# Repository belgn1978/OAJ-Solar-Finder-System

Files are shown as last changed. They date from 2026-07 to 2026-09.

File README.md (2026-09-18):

# OAJ Solar Finder System

A modular, 3D-printable projection finder for safely aligning a filtered telescope with the Sun. The telescope-specific foot is separated from the universal finder body, so future adapters can reuse the same optical assembly.

## Prototype P1

P1 is ready for its first fit and sunlight test. The printable set contains:

- `OAJ_SFS_P1_body.stl` — universal 90 mm finder body
- `OAJ_SFS_P1_nacatin_adapter.stl` — adapter for the measured Nacatin 90/800 finder shoe
- `OAJ_SFS_P1_pinhole_plate.stl` — removable front plate with a 0.8 mm pilot aperture
- `OAJ_SFS_P1_target_plate.stl` — pale rear target with recessed crosshair

The source is fully parametric in `openscad/solar_finder.scad`. Select a component with the `part` variable or run `scripts/export_stls.sh` to rebuild the complete STL set.

## How it works

Sunlight passes through the small front aperture and projects a spot onto the rear target. Centre the spot on the recessed crosshair to align the telescope. Six target positions provide pinhole-to-target distances from 45 mm to 70 mm.

## Important safety warning

This finder is a pointing aid only. It is **not** an eye-safe solar filter.

- Never look through the pinhole.
- Never look through an unfiltered telescope or finder.
- Fit a secure, certified full-aperture solar filter to the telescope before pointing it toward the Sun.
- Inspect the filter and its retention before every session.
- Supervise children continuously.

## Prototype status

The universal parts are dimensionally complete and their STL meshes have been checked as closed/manifold. The Nacatin foot is based on supplied measurements; its 5.5 mm height was estimated from photographs and must be verified by the first fit test.

See [`docs/P1_PRINT_AND_TEST_GUIDE.md`](docs/P1_PRINT_AND_TEST_GUIDE.md) before ordering or using the prototype.

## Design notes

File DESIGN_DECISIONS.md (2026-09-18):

<!-- @format -->

# Design Decisions

This document records the major architectural decisions made during the development of the OAJ Solar Finder System.

---

## DD-001

### Decision

Use a modular adapter system instead of making the telescope foot part of the main body.

### Reason

- Supports multiple telescope brands.
- Reduces waste.
- Only the adapter needs replacing when changing telescopes.
- Cheaper to manufacture and ship.
- Easier to improve individual adapters.
- Allows future accessories to use the same interface.

### Status

Approved

---

## DD-002

### Decision

Use a captured sliding dovetail with 0.25 mm clearance per side for the universal adapter interface.

### Reason

- The body cannot lift away from the adapter during use.
- The adapter prints without support.
- Fit can be tuned with one parameter after P1 testing.
- A positive front stop makes insertion repeatable.

### Status

Approved for P1

---

## DD-003

### Decision

Use separate removable pinhole and target plates, with six rigid target positions from 45 mm to 70 mm.

### Reason

- Plates can print flat for cleaner apertures and markings.
- Damaged plates can be replaced without reprinting the body.
- Multiple distances allow the first sunlight test to identify the clearest spot.
- Rigid slots are simpler and safer to validate than a folding mechanism.

### Status

Approved for P1

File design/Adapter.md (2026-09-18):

<!-- @format -->

# Adapter Design

## Purpose

The adapter connects the solar finder to a specific telescope.

Only the adapter changes between telescope models.

The rest of the system remains identical.

---

## Supported Telescopes

- Nacatin 90/800 (Current)
- Sky-Watcher (Future)
- Celestron (Future)
- SVBONY (Future)

---

## Current Measurements

### Nacatin Finder Foot

Length: 39.3 mm

Top Width: 23.8 mm

Bottom Width:
28.4 mm front
29.5 mm rear

Approx Height:
5.5 mm

Rear Notch

Width: 14.9 mm

Length: 4.2 mm

Depth: 3.5 mm

---

## Prototype geometry

The P1 adapter reproduces the measured tapered foot and rear locating notch. A short pedestal carries the universal captured-dovetail tongue above the telescope shoe.

The estimated 5.5 mm foot height is deliberately isolated in the parametric OpenSCAD source so it can be corrected after the first fit test without redesigning the universal body.

## Status

P1 STL generated; physical fit validation pending.

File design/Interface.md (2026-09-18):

<!-- @format -->

# Interface Design

## Purpose

The interface is the heart of the OAJ Solar Finder System.

Every telescope adapter connects to the main body using exactly the same interface.

This means the main body never needs redesigning when supporting a new telescope.

---

## Design Goals

- Universal connection
- Easy to print
- Strong
- Minimal supports
- Beginner friendly
- Replaceable adapters

---

## Version

Current Version: P1

---

## P1 specification

- Captured male dovetail on each telescope adapter
- Rear-entry female socket in the universal body
- 22 mm engagement length
- 16 mm neck width and 20 mm head width
- 4.5 mm dovetail height
- 0.25 mm clearance per side
- Positive front insertion stop

---

## Future Improvements

- Locking button or clip after physical fit testing
- Magnetic retention
- Quick release

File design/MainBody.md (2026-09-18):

<!-- @format -->

# Main Body

## Purpose

The main body is the permanent part of the system.

It accepts interchangeable adapters underneath and removable target plates above.

---

## P1 contains

- Adapter socket
- Six target positions at 45, 50, 55, 60, 65, and 70 mm
- Front plate mount
- Rear plate slots
- Weight-reduction pockets

---

## Design Goals

- Printable without supports
- Lightweight
- Strong
- Easy assembly
- Modular

---

## Status

P1 STL generated and mesh validated.

## Future features

- Folding plates
- Adjustable pinhole
- Optional locking clip
- Colour inserts

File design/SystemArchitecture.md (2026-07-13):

<!-- @format -->

# System Architecture

## Overview

The OAJ Solar Finder System (SFS) is designed as a modular accessory system.

The objective is to separate telescope-specific components from the universal finder body.

---

## High Level Architecture

```text
                   Rear Plate
                        ▲
                        │
                 Slides into
                        │
        ┌────────────────────────┐
        │                        │
        │      Main Body         │
        │                        │
        └────────────┬───────────┘
                     │
           Universal Interface
                     │
        ┌────────────┴───────────┐
        │                        │
        │    Telescope Adapter   │
        │                        │
        └────────────┬───────────┘
                     │
             Telescope Finder Shoe
```

---

## Core Principles

- Modular
- Easy to print
- Replaceable components
- Universal interface
- Low cost
- Beginner friendly

---

## Current Status

Architecture Design

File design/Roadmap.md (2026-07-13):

<!-- @format -->

# Roadmap

## Version 0.1

Project Setup

- Repository created
- Git configured
- VS Code configured
- OpenSCAD configured

---

## Version 0.2

Architecture

- Modular interface
- Adapter specification
- Main body specification

---

## Version 0.3

CAD

- Adapter
- Main body
- Front plate
- Rear plate

---

## Version 0.4

Prototype

- First printable version
- Initial fit testing
- Adjustment

---

## Version 0.5

Field Testing

- Solar alignment
- Ease of use
- Eclipse testing

---

## Version 1.0

Release Candidate

- Final adjustments
- Documentation
- STL release

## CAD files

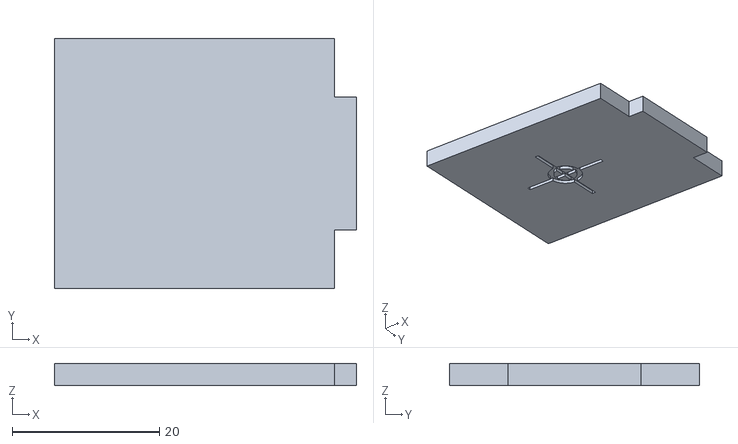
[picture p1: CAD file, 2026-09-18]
stl/OAJ_SFS_P1_target_plate.stl
41.0 x 34.0 x 3.00

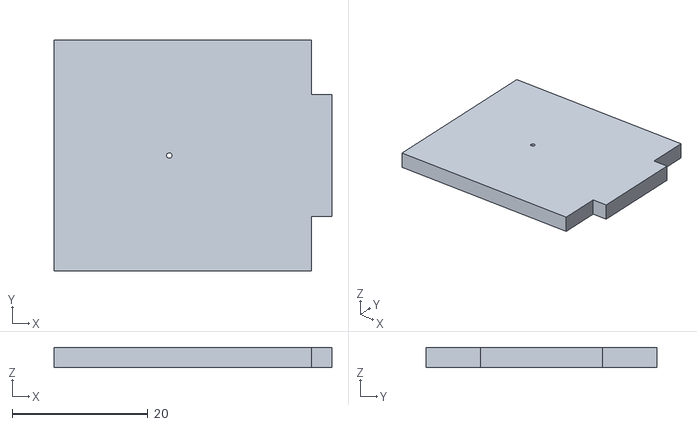
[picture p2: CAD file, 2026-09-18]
stl/OAJ_SFS_P1_pinhole_plate.stl
41.0 x 34.0 x 3.00

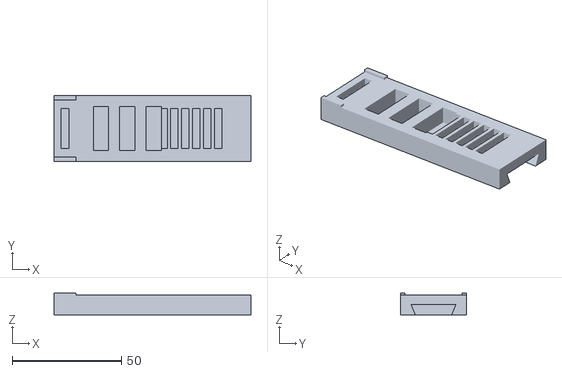
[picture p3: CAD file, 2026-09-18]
stl/OAJ_SFS_P1_body.stl
90.0 x 30.0 x 10.0

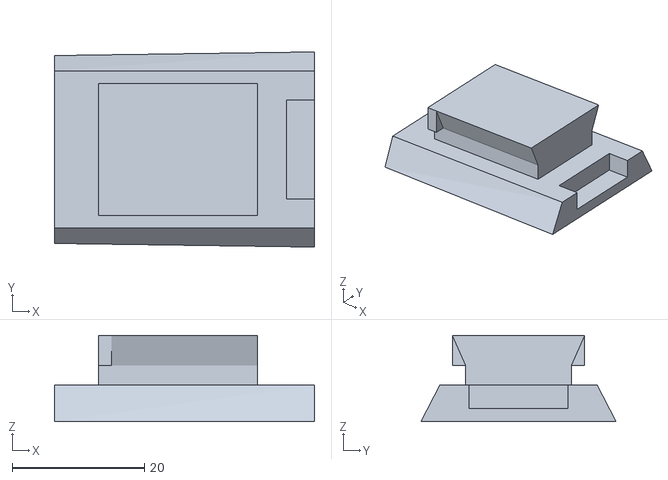
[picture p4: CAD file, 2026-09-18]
stl/OAJ_SFS_P1_nacatin_adapter.stl
39.3 x 29.5 x 13.0

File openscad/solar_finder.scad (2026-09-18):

/*
  OAJ Solar Finder System — Prototype P1

  Projection finder for solar alignment. It does not contain a lens and must
  never be looked through. A certified full-aperture solar filter is still
  required on the telescope.

  Export with, for example:
    openscad -o stl/OAJ_SFS_P1_body.stl -D 'part="body"' openscad/solar_finder.scad
*/

$fn = 64;

// Select: layout, body, nacatin_adapter, pinhole_plate, target_plate, assembly.
part = "layout";

// Printer/service tuning. This is radial/per-side clearance, not total gap.
fit_clearance = 0.25;

// Universal body and adapter interface. Keep these values unchanged when
// adding telescope-specific adapters.
body_length = 90;
body_width = 30;
body_height = 9;
socket_start = 60;
adapter_tongue_length = 22;
adapter_tongue_neck_width = 16;
adapter_tongue_head_width = 20;
adapter_tongue_height = 4.5;
adapter_stop_thickness = 2;

// Projection plates.
plate_width = 34;
plate_height = 38;
plate_thickness = 3;
plate_tab_width = 18;
plate_tab_depth = 3;
plate_slot_length = plate_thickness + (2 * fit_clearance);
plate_slot_width = plate_tab_width + (2 * fit_clearance);
front_slot_x = 5;
target_distances = [45, 50, 55, 60, 65, 70];
pinhole_diameter = 0.8; // Printed pilot; finish carefully with a 0.8 mm drill.
optical_height = 21;

// Nacatin 90/800 finder-foot measurements. The height was estimated from
// photographs and is the main fit item to verify on P1.
nacatin_foot_length = 39.3;
nacatin_foot_top_width = 23.8;
nacatin_foot_bottom_width_front = 28.4;
nacatin_foot_bottom_width_rear = 29.5;
nacatin_foot_height = 5.5;
nacatin_notch_width = 14.9;
nacatin_notch_length = 4.2;
nacatin_notch_depth = 3.5;

eps = 0.02;

module dovetail_prism(length, neck_width, head_width, height) {
    // Extrude a captured dovetail along +X.
    rotate([0, 90, 0])
        linear_extrude(height = length)
            polygon([
                [0, -neck_width / 2],
                [-height, -head_width / 2],
                [-height,  head_width / 2],
                [0,  neck_width / 2]
            ]);
}

module plate_blank() {
    // Plate plane is Y/Z; thickness is X. Tab locates in a body slot.
    union() {
        translate([-plate_thickness / 2, -plate_width / 2, 0])
            cube([plate_thickness, plate_width, plate_height]);
        translate([-plate_thickness / 2, -plate_tab_width / 2, -plate_tab_depth])
            cube([plate_thickness, plate_tab_width, plate_tab_depth + eps]);
    }
}

module finder_body() {
    difference() {
        union() {
            cube([body_length, body_width, body_height]);
            // End shoulders protect the plate tab and identify the front.
            cube([10, 2, body_height + 1]);
            translate([0, body_width - 2, 0]) cube([10, 2, body_height + 1]);
        }

        // Captured female dovetail, open at the rear for adapter insertion.
        translate([socket_start - eps, body_width / 2, -eps])
            dovetail_prism(
                body_length - socket_start + (2 * eps),
                adapter_tongue_neck_width + (2 * fit_clearance),
                adapter_tongue_head_width + (2 * fit_clearance),
                adapter_tongue_height + fit_clearance
            );

        // Fixed front-plate slot.
        translate([
            front_slot_x - plate_slot_length / 2,
            (body_width - plate_slot_width) / 2,
            body_height - plate_tab_depth
        ]) cube([plate_slot_length, plate_slot_width, plate_tab_depth + eps]);

        // Rear target positions, measured from the pinhole plane.
        for (distance = target_distances)
            translate([
                front_slot_x + distance - plate_slot_length / 2,
                (body_width - plate_slot_width) / 2,
                body_height - plate_tab_depth
            ]) cube([plate_slot_length, plate_slot_width, plate_tab_depth + eps]);

        // Weight-reduction pockets stay clear of all slots and the socket.
        for (x = [18, 30, 42])
            translate([x, 5, 2.2]) cube([7, body_width - 10, body_height]);
    }
}

module nacatin_foot() {
    // Tapered reproduction of the measured finder foot.
    difference() {
        polyhedron(
            points = [
                [0, -nacatin_foot_bottom_width_front / 2, 0],
                [0,  nacatin_foot_bottom_width_front / 2, 0],
                [nacatin_foot_length, -nacatin_foot_bottom_width_rear / 2, 0],
                [nacatin_foot_length,  nacatin_foot_bottom_width_rear / 2, 0],
                [0, -nacatin_foot_top_width / 2, nacatin_foot_height],
                [0,  nacatin_foot_top_width / 2, nacatin_foot_height],
                [nacatin_foot_length, -nacatin_foot_top_width / 2, nacatin_foot_height],
                [nacatin_foot_length,  nacatin_foot_top_width / 2, nacatin_foot_height]
            ],
            faces = [
                [0, 2, 3, 1], [4, 5, 7, 6],
                [0, 1, 5, 4], [2, 6, 7, 3],
                [0, 4, 6, 2], [1, 3, 7, 5]
            ],
            convexity = 10
        );

        // Measured rear locating notch.
        translate([
            nacatin_foot_length - nacatin_notch_length,
            -nacatin_notch_width / 2,
            nacatin_foot_height - nacatin_notch_depth
        ]) cube([
            nacatin_notch_length + eps,
            nacatin_notch_width,
            nacatin_notch_depth + eps
        ]);
    }
}

module nacatin_adapter() {
    pedestal_height = 3;
    tongue_x = (nacatin_foot_length - adapter_tongue_length) / 2;

    union() {
        nacatin_foot();
        translate([
            tongue_x - adapter_stop_thickness,
            -adapter_tongue_neck_width / 2,
            nacatin_foot_height
        ]) cube([
            adapter_tongue_length + adapter_stop_thickness,
            adapter_tongue_neck_width,
            pedestal_height
        ]);

        translate([tongue_x, 0, nacatin_foot_height + pedestal_height])
            dovetail_prism(
                adapter_tongue_length,
                adapter_tongue_neck_width,
                adapter_tongue_head_width,
                adapter_tongue_height
            );

        // Positive insertion stop at the front of the universal tongue.
        translate([
            tongue_x - adapter_stop_thickness,
            -adapter_tongue_head_width / 2,
            nacatin_foot_height + pedestal_height
        ]) cube([
            adapter_stop_thickness,
            adapter_tongue_head_width,
            adapter_tongue_height
        ]);
    }
}

module pinhole_plate_raw() {
    difference() {
        plate_blank();
        translate([0, 0, optical_height])
            rotate([0, 90, 0])
                cylinder(h = plate_thickness + 2, d = pinhole_diameter, center = true);
    }
}

module target_plate_raw() {
    groove_depth = 0.55;
    groove_width = 0.7;
    difference() {
        plate_blank();
        // Recessed crosshair on the Sun-facing side.
        translate([-plate_thickness / 2 - eps, -8, optical_height - groove_width / 2])
            cube([groove_depth + eps, 16, groove_width]);
        translate([-plate_thickness / 2 - eps, -groove_width / 2, optical_height - 8])
            cube([groove_depth + eps, groove_width, 16]);
        translate([-plate_thickness / 2 - eps, 0, optical_height])
            rotate([0, 90, 0])
                difference() {
                    cylinder(h = groove_depth + eps, d = 6);
                    translate([0, 0, -eps])
                        cylinder(h = groove_depth + (3 * eps), d = 4);
                }
    }
}

module pinhole_plate_print() {
    // Lay the broad face on the bed.
    translate([plate_height, 0, plate_thickness / 2])
        rotate([0, -90, 0]) pinhole_plate_raw();
}

module target_plate_print() {
    // Target face upwards so the shallow markings remain clean.
    translate([plate_height, 0, plate_thickness / 2])
        rotate([0, -90, 0]) target_plate_raw();
}

module assembled_preview(target_distance = 70) {
    color("DimGray") finder_body();
    color("Orange")
        translate([front_slot_x, body_width / 2, body_height]) pinhole_plate_raw();
    color("Ivory")
        translate([front_slot_x + target_distance, body_width / 2, body_height]) target_plate_raw();

    // Adapter shown inserted; it remains a separate printed component.
    adapter_tongue_local_x = (nacatin_foot_length - adapter_tongue_length) / 2;
    color("SteelBlue")
        translate([
            socket_start - adapter_tongue_local_x,
            body_width / 2,
            -(nacatin_foot_height + 3)
        ]) nacatin_adapter();
}

module print_layout() {
    finder_body();
    translate([0, 44, 0]) nacatin_adapter();
    translate([45, 55, 0]) pinhole_plate_print();
    translate([45, 100, 0]) target_plate_print();
}
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

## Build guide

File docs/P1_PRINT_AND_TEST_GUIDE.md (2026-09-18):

# P1 print and test guide

## Files to send to the print service

Send all four STL files in the `stl` folder:

1. `OAJ_SFS_P1_body.stl`
2. `OAJ_SFS_P1_nacatin_adapter.stl`
3. `OAJ_SFS_P1_pinhole_plate.stl`
4. `OAJ_SFS_P1_target_plate.stl`

All dimensions are in millimetres. Request one of each part.

## Recommended print specification

| Item | Recommendation |
| --- | --- |
| Process | FDM/FFF |
| Material | PETG preferred; ASA is also suitable |
| Layer height | 0.20 mm |
| Walls/perimeters | 4 |
| Top and bottom layers | 5 |
| Infill | 30% gyroid or cubic |
| Supports | None intended |
| Body orientation | Flat base on build plate |
| Adapter orientation | Telescope-foot base on build plate |
| Plate orientation | Broad face flat on build plate |

Print the body and pinhole plate in a dark, opaque colour. Print the target plate in white, cream, pale grey, or another light colour. A dark permanent marker or model paint can be applied to the recessed crosshair after printing.

PETG is preferred over ordinary PLA because the finder may be exposed to direct sunlight and elevated temperatures. Do not leave the device unattended in strong sunlight or in a hot vehicle.

## Critical dimensions for the print quotation

- Largest part: 90 × 30 × 10 mm
- Nacatin adapter: 39.3 × 29.5 × 13 mm
- Each plate: 41 × 34 × 3 mm in its supplied print orientation
- Universal sliding fit: 0.25 mm clearance per side
- Plate-slot fit: 0.25 mm clearance per side
- Pinhole pilot: 0.8 mm nominal

## Assembly

1. Check the Nacatin adapter in the empty finder shoe before attaching the universal body. It should insert without heavy force and should not rock excessively.
2. Slide the adapter tongue into the open rear of the body's underside socket until the positive stop reaches the front of the socket.
3. Insert the pinhole plate in the front slot with the aperture at the top.
4. Insert the target plate into the 70 mm position first. The recessed crosshair must face the pinhole plate.
5. If either printed joint is tight, lightly deburr the edges. Do not force a part into the telescope shoe.

## Pinhole finishing

FDM printers may partially close a 0.8 mm hole. Check the aperture against a bright background before assembly. If necessary, turn a 0.8 mm drill bit through the pilot **by hand**. Remove loose plastic and confirm that the opening is round and unobstructed. Do not use a powered drill while holding the plate.

## First mechanical test

| Test | Pass condition |
| --- | --- |
| Telescope foot | Slides in, seats fully, and is retained by the shoe screw/notch |
| Foot stability | No unsafe rocking or lifting |
| Universal dovetail | Slides fully to its stop without cracking or excessive play |
| Plate slots | Both plates seat vertically and remain in place when gently moved |
| Alignment | Pinhole and target centre marks appear level by eye |

The Nacatin foot height is currently estimated at 5.5 mm. Stop and revise the adapter if the telescope shoe does not retain it correctly.

## First sunlight test

1. Fit and inspect a certified full-aperture solar filter on the telescope before taking it outside.
2. Cover or remove every other optical finder.
3. Attach the solar finder and start with the target at 70 mm.
4. Without looking through any aperture, move the telescope while watching only the rear target.
5. Centre the projected spot on the target crosshair.
6. Verify the Sun is centred using the filtered main telescope at low magnification.
7. Test the remaining target positions and record which gives the clearest, easiest-to-centre spot.

Never use the projection finder as a substitute for the telescope's objective filter.

## Feedback needed for P2

- Actual Nacatin shoe fit and any required width/height correction
- Universal dovetail tightness
- Plate-slot tightness
- Best target distance
- Visibility and size of the projected spot
- Any softening, warping, or discolouration after the sunlight test

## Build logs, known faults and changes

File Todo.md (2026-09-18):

# Prototype checklist

## Completed for P1

- [x] Universal captured-dovetail interface
- [x] Nacatin 90/800 measured adapter
- [x] Universal main body
- [x] Removable front pinhole plate
- [x] Adjustable rear target plate
- [x] Six target-distance positions: 45–70 mm
- [x] Printable STL export set
- [x] Closed/manifold mesh validation
- [x] Print-service and safety guide

## Physical validation required

- [ ] Confirm Nacatin shoe insertion direction and fit
- [ ] Confirm the estimated 5.5 mm foot height
- [ ] Confirm universal dovetail slides firmly without force
- [ ] Confirm both plate tabs fit the body slots
- [ ] Finish/check the pinhole at 0.8 mm
- [ ] Perform a filtered-telescope sunlight alignment test
- [ ] Record any dimensional corrections before P2

## Future versions

- [ ] Add a positive locking clip after P1 fit testing
- [ ] Add Sky-Watcher adapter
- [ ] Add Celestron adapter
- [ ] Add SVBONY adapter
- [ ] Consider folding plates after the rigid design is validated

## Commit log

2026-07-13 file system
    [OAJ_SFS_P1.scad]
2026-07-13 Structure enhancement
    [solar_finder.scad]
2026-09-18 feat: complete P1 printable solar finder prototype
    [OAJ_SFS_P1_body.stl, OAJ_SFS_P1_nacatin_adapter.stl, OAJ_SFS_P1_pinhole_plate.stl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]
